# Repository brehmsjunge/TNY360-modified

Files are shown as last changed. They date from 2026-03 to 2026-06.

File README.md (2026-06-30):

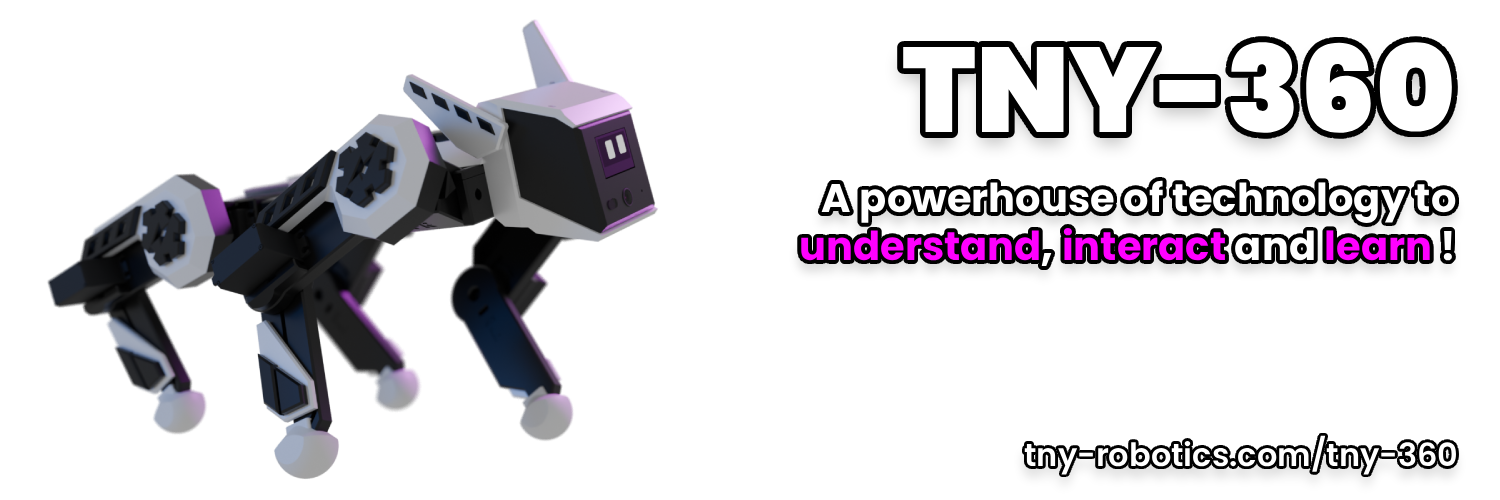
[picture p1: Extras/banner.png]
Banner


<div align="center">

# TNY-360 Modified — by Fuffel






**A modified fork of the TNY-360 open-source quadruped robot.**  
**Goal: Transform T360 into an autonomous scout & rescue platform.**

[🌐 Original Project](https://tny-robotics.com/tny-360) • [📖 Original Docs](https://tny-robotics.com/docs/tny-360/) • [💬 Discord](https://discord.gg/XGABkx5A4y) • [👤 FurWaz / Paul Loisil](https://instagram.com/furwaz_)

</div>

---

## ⚠️ This is a Fork

This repository is a **personal modification** of the original [TNY-360 by Paul Loisil / FurWaz (TNY Robotics)](https://github.com/TNY-Robotics/TNY-360).

All credit for the original robot design, firmware architecture, electronics, and documentation goes to **Paul Loisil and the TNY Robotics team**.  
This fork documents my own modifications and extensions on top of their work.

---

## 🔧 My Modifications

🚧 In Progress

- USB Serial Dashboard Transport (SerialTransport.hpp/.cpp) -> Access the robot dashboard over USB instead of WiFi only.
- Desktop Dashboard App -> A desktop application wrapping the existing WebPortal dashboard, with a switchable connection mode —> WiFi (WebSocket, same as today) or USB Serial (no need to swap WiFi networks).

📋 Planned

Active Cooling
- 2x 30x30mm 12V fans mounted on the top cover -> One intake (cold air in), one exhaust (warm air out) —> airflow across the Buck Converter and PCBs / New top cover design with fan cutouts (OpenSCAD, replacing the logo cover).
- Arduino I2C Sensor Integration -> Arduino Uno as I2C sensor node (LiDAR data), feeding into the TNY-360 mainboard via the dorsal expansion port / Later upgrade: Arduino Uno Q (Linux + MCU) for on-device AI processing.
- LiDAR + Thermal Camera Expansion -> For autonomous navigation (SLAM) and person detection
- Autonomous Navigation (SLAM) -> Path planning + obstacle avoidance using LiDAR data / Target: Arduino Uno Q running ROS2 / Nav2 as master, TNY-360 mainboard as movement slave.
- Reinforcement Learning Gait -> Teaching T360 to walk using AI instead of pre-programmed gaits.

---

## 🚀 Getting Started

For building and assembling the base robot, **follow the original guide:**

<div align="center">

> ### **[👉 Original Step-by-Step Guide by TNY Robotics 👈](https://tny-robotics.com/docs/tny-360/practical-guide/sourcing)**

</div>

For my modifications, see the relevant folders and their own READMEs:
- `Firmware/src/network/SerialTransport.cpp` — USB Serial Transport
- `CAD/cooling/` — Fan cover OpenSCAD files *(coming soon)*

---

## ⚙️ Original Hardware Specs

*(Unchanged from original — see [TNY Robotics documentation](https://tny-robotics.com/docs/tny-360/) for full details)*

| Component | Spec |
|---|---|
| MCU | ESP32-S3 N16R8 |
| Power | 3S LiPo (6x Samsung INR18650-25R) |
| Legs | 12x MG996R (modified with Op-Amp feedback PCB) |
| Head | 2x SG-90 Micro Servos |
| Vision | OV2640 Camera |
| Distance | VL53L0X ToF LiDAR |
| IMU | MPU6050 |
| Display | SH1106 OLED |
| Audio | I2S MEMS Mic + Speaker |

---

## 📂 Repository Structure

- `BOM/` — Bill of Materials (original)
- `CAD/` — Hardware files (original + my additions in `CAD/cooling/`)
- `Electronics/PCBs/` — PCB Designs (original)
- `Firmware/` — Codebase with my modifications on top of the original
- `Firmware/src/network/SerialTransport.cpp` — USB Serial Transport (my addition)

---

## 📄 License & Credits

**Original TNY-360** by [Paul Loisil / FurWaz](https://instagram.com/furwaz_) — [TNY Robotics](https://tny-robotics.com)  
**This fork** by Fuffel (Felix Brehm)

Licensed under **CC BY-NC-SA 4.0** — non-commercial use, attribution required, share alike.



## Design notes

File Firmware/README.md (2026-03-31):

# Firmware

Welcome to the TNY-360 Firmware directory! This is where all the code that powers the TNY-360 robot lives.

The firmware is built on **PlatformIO** using the **ESP-IDF** framework.

## Quick Start

### Prerequisites
1.  **VS Code** installed.
2.  **PlatformIO** extension installed in VS Code.

### Installation
1.  **Clone** this repository:
    ```bash
    git clone --recursive https://github.com/TNY-Robotics/TNY-360.git
    ```
2.  **Open** the `Firmware/` folder in VS Code.
3.  **Connect** your ESP32-S3 N16R8 via USB.
4.  **Upload:** Click the generic "Arrow" icon (➡️) in the PlatformIO bottom bar to Build & Flash.

> **Note:** If you are missing drivers, run `git submodule update --init --recursive` to pull the TNY-Robotics custom components.

---

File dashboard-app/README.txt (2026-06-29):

TNY-360 Dashboard Desktop App
==============================

A native Windows desktop application for controlling the TNY-360 quadruped robot
without needing a browser or switching network connections manually.

HOW IT WORKS
-------------
- The app bundles the existing WebPortal (Nuxt/Vue.js) and serves it locally via
  a built-in HTTP server on http://127.0.0.1:3333
- It connects to the TNY-360 via WebSocket on ws://192.168.4.1:5621 (default AP IP)
- The robot IP is set automatically via localStorage on first launch

REQUIREMENTS
-------------
- Windows 10/11
- Node.js and npm (for building)
- TNY-360 robot powered on and in Access Point (AP) WiFi mode
- PC connected to the TNY-360 WiFi network

BUILD FROM SOURCE
------------------
1. Build the WebPortal:
   cd Firmware/extras/WebPortal
   npm install
   npm run generate

2. Build the Electron app:
   cd dashboard-app
   npm install
   npx electron-builder

   Output: dashboard-app/dist/TNY-360 Dashboard Setup 1.0.0.exe

3. Run the installer and launch "TNY-360 Dashboard" from the desktop or start menu.

USAGE
------
1. Power on the TNY-360
2. Connect your PC to the TNY-360 WiFi network
3. Open the TNY-360 Dashboard app
4. The app will automatically connect to the robot at 192.168.4.1

PROJECT STRUCTURE
------------------
dashboard-app/
  main.js        - Electron main process, HTTP server, window setup
  preload.js     - Electron preload script (bridge for future USB Serial)
  package.json   - Node.js project config + electron-builder config

The WebPortal files are bundled from:
  Firmware/extras/WebPortal/.output/public/
(generated via "npm run generate" in the WebPortal directory)

TECHNICAL NOTES
----------------
- The app uses a local HTTP server instead of file:// protocol because Nuxt
  generates absolute asset paths (/_nuxt/...) that don't work with Electron's
  file:// loader.
- On first load, the app injects localStorage.setItem('fallback_ip', '192.168.4.1')
  so the WebPortal SDK connects to the correct robot IP instead of 127.0.0.1.
- USB Serial support is planned for a future version (SerialTransport.hpp is
  already implemented on the firmware side).

PLANNED FEATURES
-----------------
- USB Serial connection (no WiFi needed)
- WiFi <-> USB toggle in the UI
- Custom IP input dialog

CREDITS
--------
- TNY-360 robot & WebPortal: Paul Loisil (FurWaz) / TNY Robotics
  https://github.com/TNY-Robotics/TNY-360
- Dashboard Desktop App: Community contribution

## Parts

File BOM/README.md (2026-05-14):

# Bill Of Material

Here's the raw List of components you need to build your own TNY-360 robot.

You can also find a more user-friendly version of this list on the [TNY-360 Documentation](https://tny-robotics.com/docs/tny-360/practical-guide/sourcing/) as well as guides and manuals to help you source, print, assemble, and set up your TNY-360!

- List of [Screws and Inserts](./Screws.md)

- List of [Cables](./Cables.md)

- List of [PCBs](./PCBs.md)

- List of [Components](./Components.md)

*Have fun building your robot!*

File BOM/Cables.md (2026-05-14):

# Cables

Here's a list of all cables needed to wire up your TNY-360.

A complete kit of JST-PH wires is also linked below for easier sourcing, instead of buying each cable independently.

### Assembly guide

To learn how to fully assemble you TNY-360, check out the [TNY-360 Documentation](https://tny-robotics.com/docs/tny-360/practical-guide/sourcing/). A more user-friendly list of all the cables needed is also available here.

| Type | Pins | Length | Quantity | Location | Link |
| :--- | :--: | :----- | :---: | :--- | :--- |
| JST-PH |  3 | 100 mm | 4 | Motor Driver -> Paw Board | [Click here](https://s.click.aliexpress.com/e/_c3BIp6Ux) |
| JST-PH |  2 | 100 mm | 1 | Motor Driver -> Main Board | [Click here](https://s.click.aliexpress.com/e/_c3BIp6Ux) |
| JST-PH |  5 | 100 mm | 1 | Motor Driver -> Main Board | [Click here](https://s.click.aliexpress.com/e/_c3BIp6Ux) |
| JST-PH |  4 | 100 mm | 4 | Analog Reader -> Paw Board | [Click here](https://s.click.aliexpress.com/e/_c3BIp6Ux) |
| JST-PH |  7 | 100 mm | 1 | Analog Reader -> Main Board | [Click here](https://s.click.aliexpress.com/e/_c3BIp6Ux) |
| JST-PH (PIGTAIL) |  4 | 200 mm | 1 | IMU -> Paw Board | [Click here](https://s.click.aliexpress.com/e/_c44pILQb) |
| JST-PH |  4 | 200 mm | 2 | Plug Board -> Power & Main Board | [Click here](https://s.click.aliexpress.com/e/_c3BIp6Ux) |
| JST-PH |  2 | 200 mm | 2 | Plug Board -> Power & Main Board | [Click here](https://s.click.aliexpress.com/e/_c3BIp6Ux) |
| JST-PH (PIGTAIL) |  4 | 50 mm  | 1 | SH1106 -> Main Board | [Click here](https://s.click.aliexpress.com/e/_c44pILQb) |
| JST-PH (PIGTAIL) |  3 | 50 mm  | 2 | TTP23 -> Main Board | [Click here](https://s.click.aliexpress.com/e/_c44pILQb) |
| JST-PH (PIGTAIL) |  4 | 50 mm  | 1 | VL53L0X -> Main Board | [Click here](https://s.click.aliexpress.com/e/_c44pILQb) |
| JST-PH (PIGTAIL) |  5 | 50 mm  | 1 | I2S Mic. -> Main Board | [Click here](https://s.click.aliexpress.com/e/_c44pILQb) |
| JST-PH (PIGTAIL) |  2 | 450 mm | 4 | Contact Switch -> Paw Board | [Click here](https://s.click.aliexpress.com/e/_c44pILQb) |
| JST-XH (PIGTAIL) |  4 | 100 mm | 8 | Shoulder Servo -> Paw Board | [Click here](https://s.click.aliexpress.com/e/_c3WRxkg7) |
| JST-XH (PIGTAIL) |  4 | 300 mm | 4 | Leg Servo -> Paw Board | [Click here](https://s.click.aliexpress.com/e/_c3WRxkg7) |
| JST-XH (PIGTAIL) |  4 | 300 mm | 4 | Leg Servo -> Paw Board | [Click here](https://s.click.aliexpress.com/e/_c3WRxkg7) |
| 16 AWG Wire | | 100 mm | 3 | DC-DC Converter -> Paw Board | [Click here](https://fr.aliexpress.com/item/1005006614755156.html) |

### Connectors
| Type | Quantity | Link |
| --- | --- | --- |
| Ring Crimp Connector | 6 | [Click here](https://s.click.aliexpress.com/e/_c2yxJCd5) |
| Dupont Connector | 4 | None - Use the ones from the MG996R motors :) |

### Complete kit

To simplify cable sourcing, you can alternatively buy only one JST-PH cable kit, and some JST-XH pigtail cables.

* Link to the [JST-PH Cables Kit](https://s.click.aliexpress.com/e/_c3AtPZ9h).
* Link to the [Dupont Connector Kit](https://fr.aliexpress.com/item/4001063470283.html);
* Link to the [JST-XH Pigtail Cables](https://s.click.aliexpress.com/e/_c3WRxkg7).

Please check that you selected the `XH-2.54mm version (4P)` before ordering.

### About the SH1106, TTP23, VL53L0X and I2S Mic. cables

Since these cables are going to be soldered directly on the component, you can buy a 100mm cable and cut it in half to make 2x 50mm pigtail cables. This reduces the number of cables to order.

### About the contact switch cable

The contact switch cable should end with a 3-pin Dupont connector (the standard 2.54mm arduino connectors), with the middle pin empty.

No such cable (JST-PH 2-Pins to 2.54 mm Dupont 3 Pins) exists on the web, so you will probably have to make it yourself. A complete guide on how to create that cable is available *(or will be available)* on the [TNY-360 Documentation](https://tny-robotics.com/docs/tny-360).

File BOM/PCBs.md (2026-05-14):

# PCBs

Here's a list of all PCBs needed to build your TNY-360. You can find all design files in the [GitHub repository](https://github.com/TNY-Robotics/TNY-360/tree/main/Electronics/PCBs).

### Assembly guide

To learn how to fully assemble you TNY-360, check out the [TNY-360 Documentation](http://localhost:3000/docs/tny-360/practical-guide/sourcing/). A more user-friendly list of all the PCBs needed is also available here.

### PCBs list

| PCB | Purpose | Quantity | Files |
| --- | --- | :---: | --- |
| Main Board | Robot brain and main controller | 1 | [GitHub PCB Files](https://github.com/TNY-Robotics/TNY-360/tree/main/Electronics/PCBs/Main) |
| Analog Reader | Sensor interface board | 1 | [GitHub PCB Files](https://github.com/TNY-Robotics/TNY-360/tree/main/Electronics/PCBs/Analog%20Reader) |
| Motor Driver  | Motor control board | 1 | [GitHub PCB Files](https://github.com/TNY-Robotics/TNY-360/tree/main/Electronics/PCBs/Motor%20Driver) |
| Power Board | Power distribution | 1 | [GitHub PCB Files](https://github.com/TNY-Robotics/TNY-360/tree/main/Electronics/PCBs/Power) |
| Paw Board | Legs multiplexing and power management | 2 | [GitHub PCB Files](https://github.com/TNY-Robotics/TNY-360/tree/main/Electronics/PCBs/Paw) |
| Plug Board | Universal Mount interface | 1 | [GitHub PCB Files](https://github.com/TNY-Robotics/TNY-360/tree/main/Electronics/PCBs/Universal%20Mount) |
| Servo Board | Custom MG996R servo modification board | 12 | [GitHub PCB Files](https://github.com/TNY-Robotics/TNY-360/tree/main/Electronics/PCBs/Servomotor) |

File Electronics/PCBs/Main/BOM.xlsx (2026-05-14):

No. | Quantity | Comment | Designator | Footprint | Value | Manufacturer Part | Manufacturer | Supplier Part | Supplier
1 | 1 | XL-5050RGBC-2812B | 2812B | LED-SMD_4P-L5.0-W5.0-BL_XL-5050RGBC |  | XL-5050RGBC-2812B | XINGLIGHT(成兴光) | C2843785 | LCSC
2 | 2 | AMS1117-3.3 | AMS3.3,AMS3.3ESP | SOT-223-3_L6.5-W3.4-P2.30-LS7.0-BR |  | AMS1117-3.3 | AMS | C6186 | LCSC
3 | 2 | B3B-PH-K-S(LF)(SN) | BTN_LEFT,BTN_RIGHT | CONN-TH_B3B-PH-K-S |  | B3B-PH-K-S(LF)(SN) | JST | C131339 | LCSC
4 | 1 | HX 0.5-24PIN XGXJ-H2.0 | CAM | FPC-SMD_24P-P0.50_HX-0.5-24PIN-XGXJ-H2.0 |  | HX 0.5-24PIN XGXJ-H2.0 | hanxia(韩下) | C19269981 | LCSC
5 | 3 | 220pF | CASIG,CSPKRG,CSPKRV | C0603 | 220pF | CL10B221KB8NNNC | SAMSUNG(三星) | C1603 | LCSC
6 | 4 | 10uF | CAVDD2,CCH340,CDVDD2,CESP2 | C0603 | 10uF | CL10A106MA8NRNC | SAMSUNG(三星) | C96446 | LCSC
7 | 8 | 100nF | CAVDD,CAVDD1,CCAM14,CCSI_RST,CDVDD1,CESP1,CINL,CSPKR | C0603 | 100nF | CC0603KRX7R9BB104 | YAGEO(国巨) | C14663 | LCSC
8 | 1 | 15pF | CCAM8 | C0603 | 15pF | CL10C150JB8NNNC | SAMSUNG(三星) | C1644 | LCSC
9 | 1 | CH340C | CH340C | SOP-16_L10.0-W3.9-P1.27-LS6.0-BL |  | CH340C | WCH(南京沁恒) | C84681 | LCSC
10 | 3 | 1uF | CINR1,CUPEN1,CVREF | C0603 | 1uF | CL10A105KO8NNNC | SAMSUNG(三星) | C1592 | LCSC
11 | 1 | 10nF | CINR2 | C0603 | 10nF | 0603B103K500NT | FH(风华) | C57112 | LCSC
12 | 4 | B4B-PH-K-S(LF)(SN) | CN-BAT,CN-IMU,CN-LASER,CN-SCREEN | CONN-TH_B4B-PH-K-S |  | B4B-PH-K-S(LF)(SN) | JST | C131334 | LCSC
13 | 2 | B2B-PH-K-S(LF)(SN) | CN-EARS,CN-POWER | CONN-TH_B2B-PH-K-S |  | B2B-PH-K-S(LF)(SN) | JST | C131337 | LCSC
14 | 2 | B5B-PH-K-S(LF)(SN) | CN-MOTORS,MIC | CONN-TH_B5B-PH-K-S-LF-SN |  | B5B-PH-K-S(LF)(SN) | JST | C157993 | LCSC
15 | 1 | B7B-PH-K-S(LF)(SN) | CN-READER | CONN-TH_B7B-PH-K-S-LF-SN |  | B7B-PH-K-S(LF)(SN) | JST | C157981 | LCSC
16 | 1 | 470uF | CPGND | CAP-TH_BD8.0-P3.50-D0.6-FD | 470uF | GR477M025F14RR0VL4FP0 | Chengx(承兴) | C5154 | LCSC
17 | 2 | SS34 | D1,D2 | SMA_L4.3-W2.6-LS5.2-RD |  | SS34 | MDD(辰达半导体) | C8678 | LCSC
18 | 1 | ESP32-S3-WROOM-1U-N16R8 | ESP32-S3 | WIRELM-SMD_ESP32-S3-WROOM-1U |  | ESP32-S3-WROOM-1U-N16R8 | ESPRESSIF(乐鑫) | C3013946 | LCSC
19 | 3 | BLM18SG121TN1D | LAVDD,LSPKRG,LSPKRV | L0603 |  | BLM18SG121TN1D | muRata(村田) | C113030 | LCSC
20 | 1 | PAM8406DR | PAM8406 | SOIC-16_L9.9-W3.9-P1.27-LS6.0-BL |  | PAM8406DR | DIODES(美台) | C86270 | LCSC
21 | 2 | S8050 J3Y(RANGE:200-350) | QDTR,QRTS | SOT-23-3_L3.0-W1.7-P0.95-LS2.9-BR |  | S8050 J3Y(RANGE:200-350) | CJ(江苏长电/长晶) | C2146 | LCSC
22 | 2 | 1kΩ | RCAM17,RINR | R0603 | 1kΩ | RC0603FR-071KL | YAGEO(国巨) | C22548 | LCSC
23 | 3 | 10kΩ | RDTR,RRTS,RUPEN1 | R0603 | 10kΩ | 0603WAF1002T5E | UNI-ROYAL(厚声) | C25804 | LCSC
24 | 1 | 22kΩ | RPAM | R0603 | 22kΩ | 0603WAF2202T5E | UNI-ROYAL(厚声) | C31850 | LCSC
25 | 1 | 4.7kΩ | RRST | R0603 | 4.7kΩ | 0603WAF4701T5E | UNI-ROYAL(厚声) | C23162 | LCSC
26 | 4 | 2.2kΩ | RUPFA,RUPFL,RUPSA,RUPSL | R0603 | 2.2kΩ | 0603WAF2201T5E | UNI-ROYAL(厚声) | C4190 | LCSC
27 | 1 | 1.25mm-2P ZZ-MS | SPEAKER | CONN-TH_2P-P1.25_1.25MM-2P-ZZ-MS |  | 1.25mm-2P ZZ-MS | SHOU HAN(首韩) | C5368706 | LCSC
28 | 1 | TYPE-C16PIN | USB | USB-C-SMD_TYPE-C16PIN |  | TYPE-C16PIN | SHOU HAN(首韩) | C393939 | LCSC
29 | 1 | USBLC6-2SC6 | USBLC6 | SOT-23-6_L2.9-W1.6-P0.95-LS2.8-BL |  | USBLC6-2SC6 | ST(意法半导体) | C7519 | LCSC
30 | 1 | XC6206-1.2V | XC6206-1.2 | SOT-23-3_L3.0-W1.6-P1.90-LS2.8-BR |  | XC6206-1.2V | YONGYUTAI(永裕泰) | C49446790 | LCSC
31 | 1 | XC6206-2.8V | XC6206-2.8 | SOT-23-3_L2.9-W1.6-P1.90-LS2.8-BR |  | XC6206-2.8V | YONGYUTAI(永裕泰) | C2892669 | LCSC

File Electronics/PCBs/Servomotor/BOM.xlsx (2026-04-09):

No. | Quantity | Comment | Designator | Footprint | Value | Manufacturer Part | Manufacturer | Supplier Part | Supplier
1 | 1 | 100nF | C1 | C0402 | 100nF | CL05B104KO5NNNC | SAMSUNG(三星) | C1525 | LCSC
2 | 1 | OPA333AIDCKT | U1 | SC-70-5_L2.0-W1.3-P0.65-LS2.1-BL |  | OPA333AIDCKT | TI(德州仪器) | C2057324 | LCSC

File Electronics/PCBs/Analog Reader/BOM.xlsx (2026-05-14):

No. | Quantity | Comment | Designator | Footprint | Value | Manufacturer Part | Manufacturer | Supplier Part | Supplier
1 | 1 | 74HC4067PW,118 | 74HC4067 | TSSOP-24_L7.8-W4.4-P0.65-LS6.4-BL |  | 74HC4067PW,118 | Nexperia(安世) | C179326 | LCSC
2 | 16 | 1uF | C1,C2,C3,C4,C5,C6,C7,C8,C9,C10,C11,C12,C13,C14,C15,C16 | C0603 | 1uF | CL10A105KB8NNNC | SAMSUNG(三星) | C15849 | LCSC
3 | 1 | 100nF | C-74HC | C0805 | 100nF | CC0805KRX7R9BB104 | YAGEO(国巨) | C49678 | LCSC
4 | 4 | B4B-PH-K-S(LF)(SN) | CN-BL,CN-BR,CN-FL,CN-FR | CONN-TH_B4B-PH-K-S |  | B4B-PH-K-S(LF)(SN) | JST | C131334 | LCSC
5 | 1 | B7B-PH | CN-SIGNAL | CONN-TH_B7B-PH-K-S-LF-SN |  | B7B-PH | JST | C157981 | LCSC
6 | 16 | 4.7kΩ | R1,R2,R3,R4,R5,R6,R7,R8,R9,R10,R11,R12,R13,R14,R15,R16 | R0603 | 4.7kΩ | 0603WAF4701T5E | UNI-ROYAL(厚声) | C23162 | LCSC

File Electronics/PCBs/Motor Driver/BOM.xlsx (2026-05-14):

No. | Quantity | Comment | Designator | Footprint | Value | Manufacturer Part | Manufacturer | Supplier Part | Supplier
1 | 2 | 100nF | C-LS,C-PCA | C0805 | 100nF | CC0805KRX7R9BB104 | YAGEO(国巨) | C49678 | LCSC
2 | 4 | B3B-PH-K-S(LF)(SN) | CN-BL,CN-BR,CN-FL,CN-FR | CONN-TH_B3B-PH-K-S |  | B3B-PH-K-S(LF)(SN) | JST | C131339 | LCSC
3 | 1 | B2B-PH-K-S(LF)(SN) | CN-EARS | CONN-TH_B2B-PH-K-S |  | B2B-PH-K-S(LF)(SN) | JST | C131337 | LCSC
4 | 1 | B5B-PH-K-S(LF)(SN) | CN-SIGNAL | CONN-TH_B5B-PH-K-S-LF-SN |  | B5B-PH-K-S(LF)(SN) | JST | C157993 | LCSC
5 | 1 | PCA9306DCUR | PCA9306 | SSOP-8_L2.0-W2.3-P0.50-LS3.1-BR |  | PCA9306DCUR | TI(德州仪器) | C33196 | LCSC
6 | 1 | PCA9685PW,118 | PCA9685 | TSSOP-28_L9.7-W4.4-P0.65-LS6.4-TL | - | PCA9685PW,118 | NXP(恩智浦) | C2678753 | LCSC
7 | 14 | 220Ω | R1,R2,R3,R4,R5,R6,R7,R8,R9,R10,R11,R12,R13,R14 | R0805 | 220Ω | 0805W8F2200T5E | UNI-ROYAL(厚声) | C17557 | LCSC
8 | 1 | 200kΩ | R-LS | R0805 | 200kΩ | 0805W8F2003T5E | UNI-ROYAL(厚声) | C17539 | LCSC
9 | 2 | 2.2kΩ | RUP1,RUP2 | R0805 | 2.2kΩ | 0805W8F2201T5E | UNI-ROYAL(厚声) | C17520 | LCSC

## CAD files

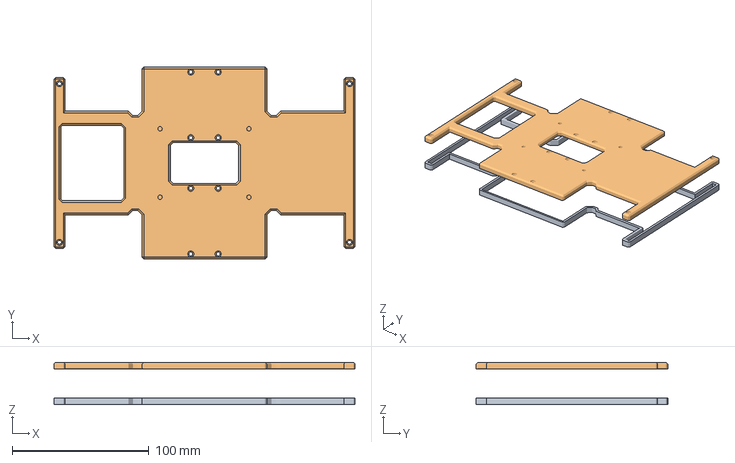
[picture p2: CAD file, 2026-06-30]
CAD/01_Parts/Spacer.FCStd
220.0 x 140.0 x 31.0 mm
Torso - Top

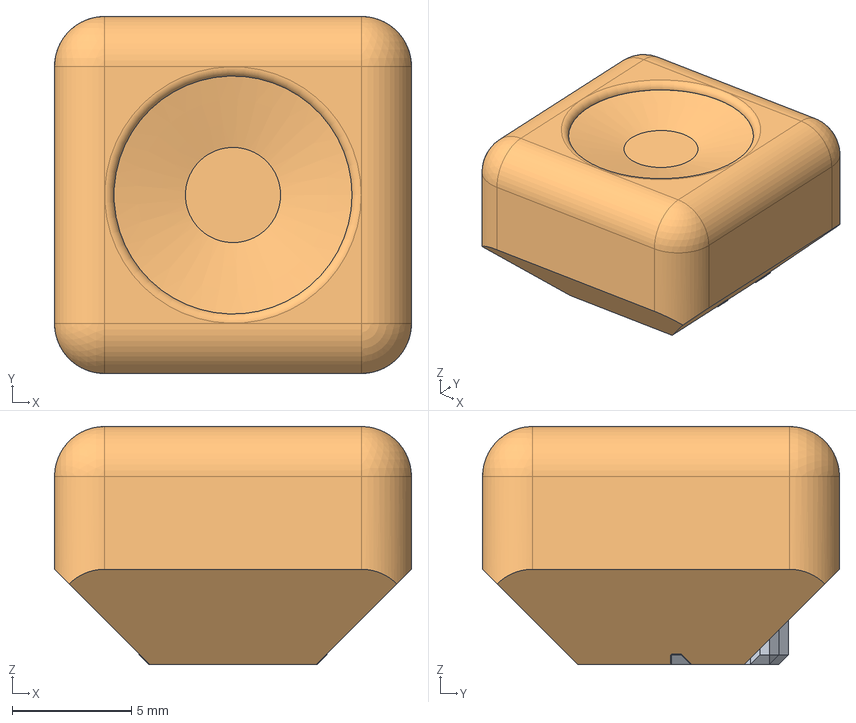
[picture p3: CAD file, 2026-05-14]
CAD/03_Common/Master_Clip.FCStd
15.0 x 15.0 x 10.0 mm
Clip
ClipHelper

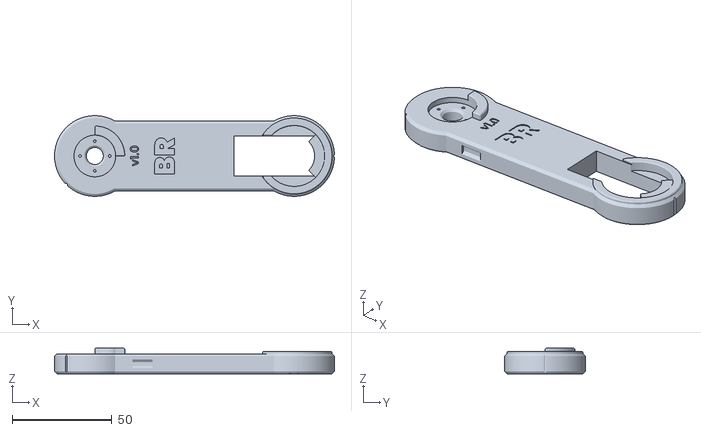
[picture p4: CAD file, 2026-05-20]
CAD/Exported/STLs/Leg - Top BR.stl
140.5 x 40.5 x 12.8

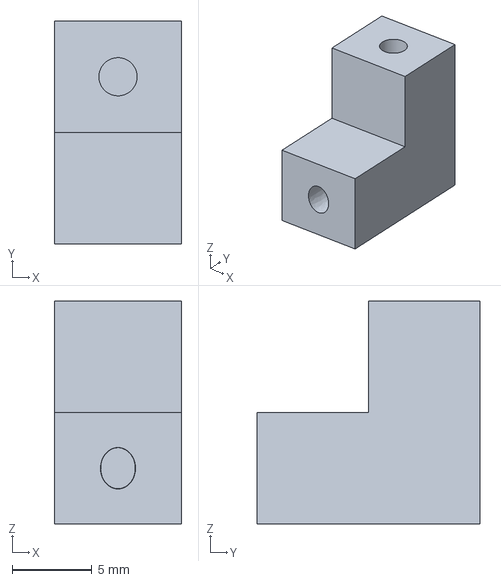
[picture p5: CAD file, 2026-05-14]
CAD/Settings.FCStd
8.00 x 14.0 x 14.0 mm

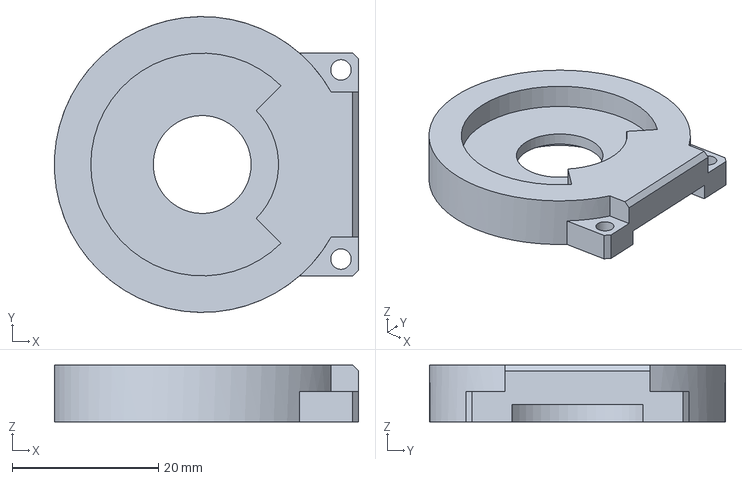
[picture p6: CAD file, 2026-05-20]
CAD/01_Parts/Shoulders.FCStd
41.6 x 40.5 x 7.80 mm

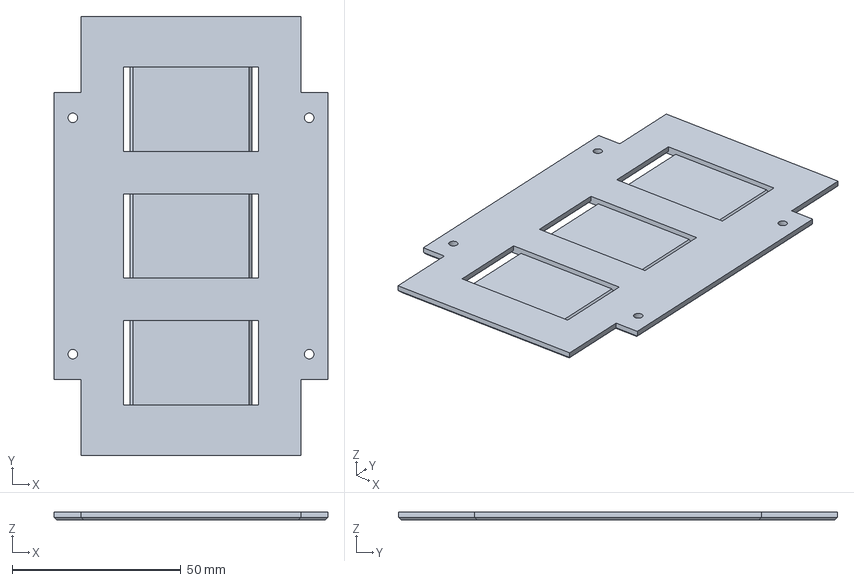
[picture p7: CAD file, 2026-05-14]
CAD/01_Parts/Battery.FCStd
81.0 x 130.0 x 2.40 mm

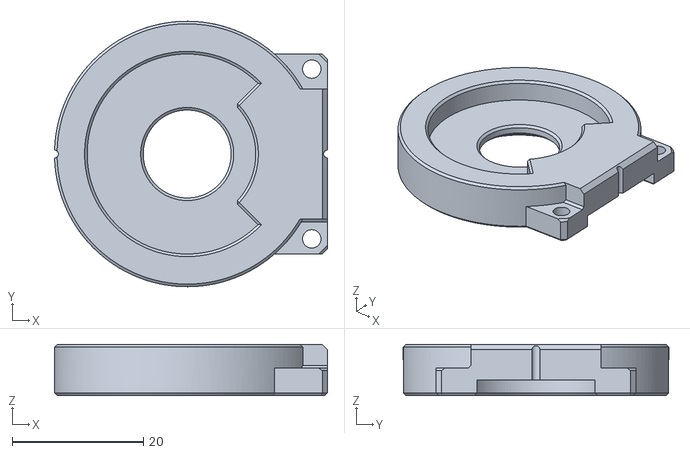
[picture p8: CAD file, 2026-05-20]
CAD/Exported/STLs/Shoulder - Top.stl
41.6 x 40.5 x 7.80

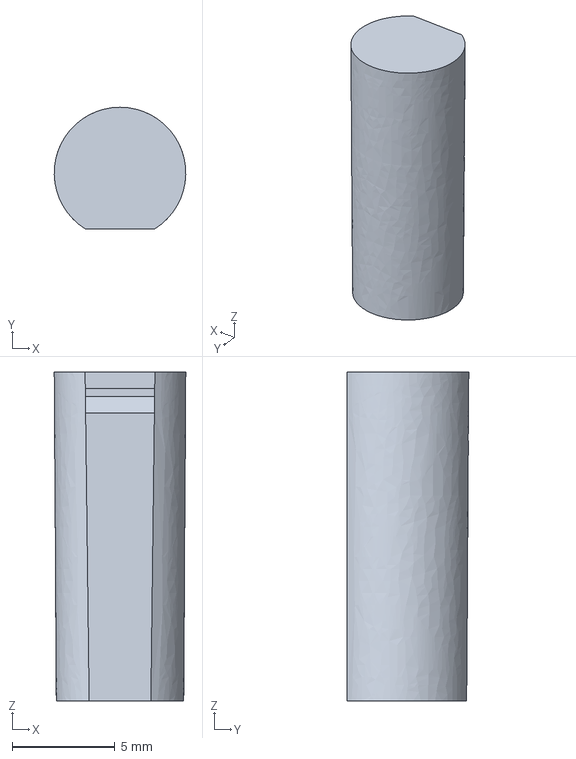
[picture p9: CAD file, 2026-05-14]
CAD/01_Parts/Torso-Shoulder_Pin.FCStd
6.40 x 5.91 x 16.0 mm

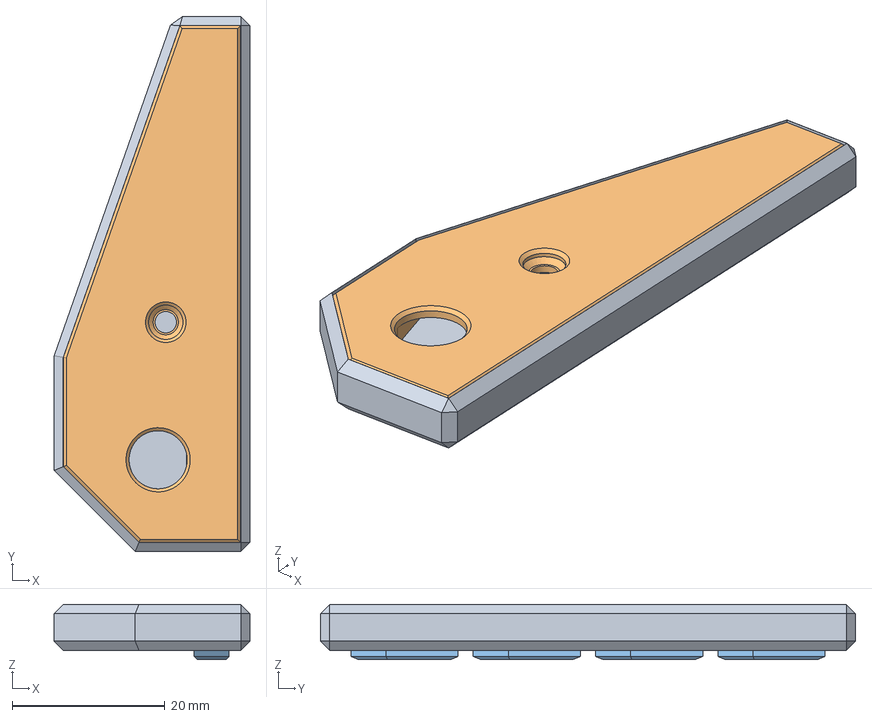
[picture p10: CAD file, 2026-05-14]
CAD/01_Parts/Ears.FCStd
25.6 x 70.0 x 7.20 mm
Front - L
Back - L
Deco - L

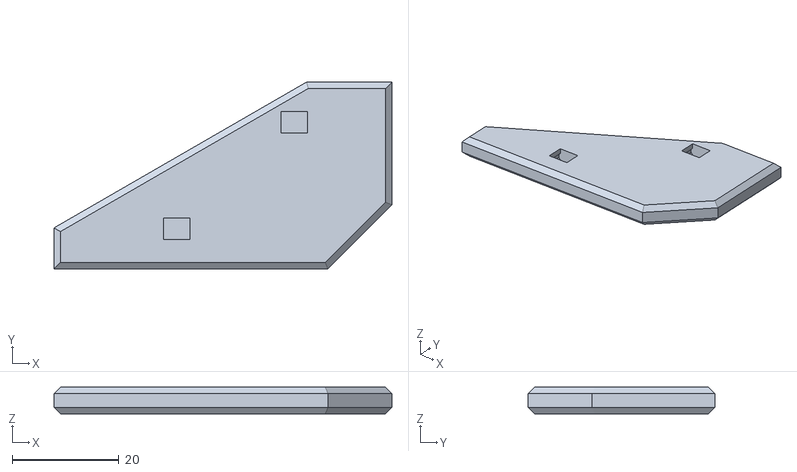
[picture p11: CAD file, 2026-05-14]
CAD/Exported/STLs/Leg - Bottom L - Cover.stl
63.3 x 35.0 x 5.00

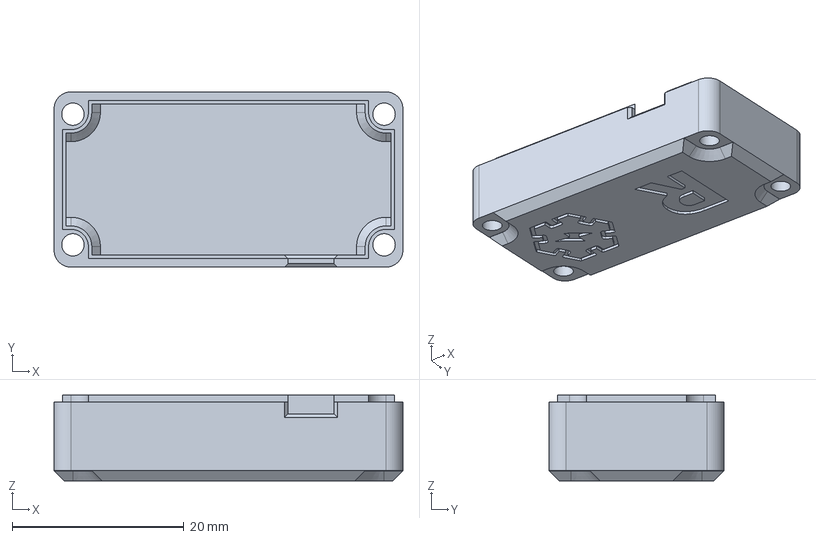
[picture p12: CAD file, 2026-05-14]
CAD/01_Parts/Servo_Cover.FCStd
40.6 x 20.4 x 10.0 mm

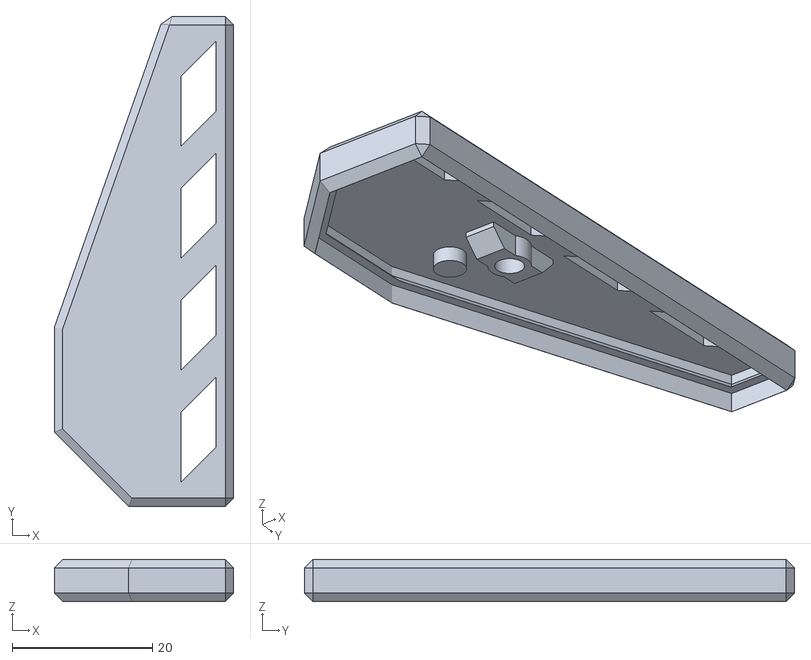
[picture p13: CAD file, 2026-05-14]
CAD/Exported/STLs/Ears - Front R.stl
25.6 x 70.0 x 6.00

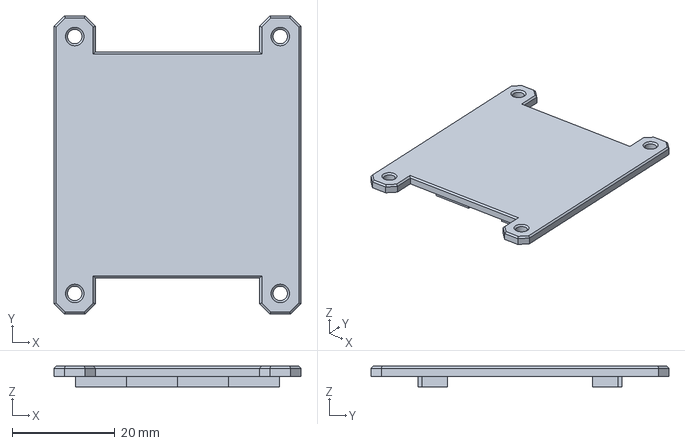
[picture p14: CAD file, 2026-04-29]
CAD/01_Parts/Torso.FCStd
48.0 x 58.0 x 4.00 mm

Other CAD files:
CAD/00_Assemblies/Main.FCStd
CAD/Exported/STLs/Leg - Top FR.stl
CAD/01_Parts/Leg_Top.FCStd
CAD/Exported/STLs/Leg - Top BL.stl
CAD/Exported/STLs/Leg - Top FL.stl
CAD/01_Parts/Back.FCStd
CAD/01_Parts/Leg_Bottom.FCStd
CAD/Exported/STLs/Back - Bottom Clip.stl
CAD/Exported/STLs/Back - Cover.stl
CAD/Exported/STLs/Battery - LipoHolder Base.stl
CAD/Exported/STLs/Clip - Helper.stl
CAD/Exported/STLs/Clip.stl
CAD/Exported/STLs/Ears - Back L.stl
CAD/Exported/STLs/Ears - Back R.stl
CAD/Exported/STLs/Ears - Deco L.stl
CAD/Exported/STLs/Ears - Deco R.stl
CAD/Exported/STLs/Ears - Front L.stl
CAD/Exported/STLs/Head - Backplate.stl
CAD/Exported/STLs/Head - Bottom Cover.stl
CAD/Exported/STLs/Head - Camera Attach.stl
CAD/Exported/STLs/Head - Top Cover.stl
CAD/Exported/STLs/Head - Visor Plate.stl
CAD/Exported/STLs/Head - Visor.stl
CAD/Exported/STLs/Leg - Bottom Ball.stl
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

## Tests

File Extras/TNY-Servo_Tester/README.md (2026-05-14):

# TNY-Servo Tester

This project is for people building their own TNY Servomotors.

It provides a simple way to ensure the servomotors work correctly before they are installed in the robot.

---

> [!NOTE]  
> The code is dirty. It is not meant to be used as a reference for good coding practices, but rather as a quick and dirty solution to test the servomotors.

## Hardware

The tester is made to work on an ESP32-S3 Dev Board, here's the pinout:

| ESP32-S3 Pin | Function |
| --- | --- |
| GPIO 48 | LED Control (WS2812) |
| GPIO 42 | Servo Signal (PWM) |
| GPIO 02 | Servo Feedback (ADC1_CH1) |

While powering up a motor from the ESP32-S3 Dev Board is not recommended, it's acceptable to power the servo from the board's **5V** & **GND** pins for testing purposes. The servo will only draw a small amount of current during the test (as long as you don't block its movement), so it should be safe to power it from the board.

For easier testing, connect a 4-Pin Dupont 2.54mm header to the ESP32-S3 Dev Board, and then connect the TNY-Servo's JST-XH connector to the header. This will allow you to easily connect and disconnect the servo for testing.

> [!WARNING]  
> Make sure to connect the **GROUND** pin of the servo first (slightly tilt the connector when plugging it in) to avoid damaging the servo or the ESP32-S3 Dev Board. If power is applied to the servo before the ground connection is made, it can cause the current to come back through the servo's internal circuitry. 

## Software

The code is written in C++ using the ESP-IDF framework. It uses the LEDC peripheral to generate the PWM signal for the servo and the ADC to read the feedback from the servo.

## Usage

1. Connect the servo to the ESP32-S3 Dev Board according to the pinout above.
2. Power on or reset the ESP32-S3 Dev Board.
3. Wait for the code to run and observe the LED color and the servo movement.
4. For more detailed information on the test, check the serial output using a serial monitor.

### Testing sequence

The testing sequence is simple :
1. The servo will move to its minimum position (0°) and wait a little bit for the ADC reading to stabilize.
2. The servo will then move to its maximum position (180°) and wait again for the ADC reading to stabilize.
3. Finally, the servo will move back to its center position (90°) and wait for the ADC reading to stabilize.

At the end of the test, the code will check if the ADC readings are within the expected range, noise & order for the servo to be considered working correctly. Even if the servo is moving during the test, the feedback could still be incorrect, so wait for the test to finish and check the LED color to know if the servo is fully functional or not.

### LED Color Indication

While testing, the LED will display in **BLUE**. This indicates that the tester is running and the servo is being tested.

At the end of the test, the LED will change to **GREEN** if the servo is working correctly, or **RED** if there is an issue with the servo.

For more information on the test results, check the serial output.

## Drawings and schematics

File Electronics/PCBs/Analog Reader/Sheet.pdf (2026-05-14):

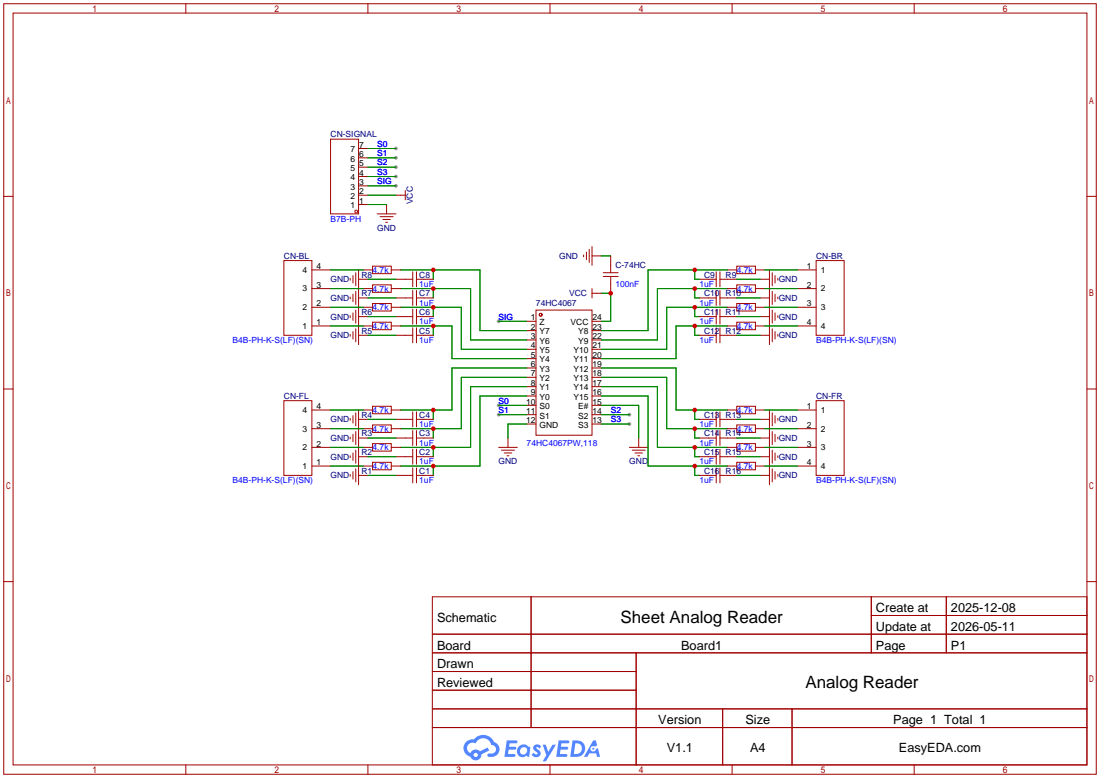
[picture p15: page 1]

Schematic | Sheet Analog Reader | Create at | 2025-12-08

Update at | 2026-05-11

Board | Board1 | Page | P1
Drawn | | Analog Reader
Reviewed

Version | Size | Page 1 Total 1
V1.1 | A4 | EasyEDA.com

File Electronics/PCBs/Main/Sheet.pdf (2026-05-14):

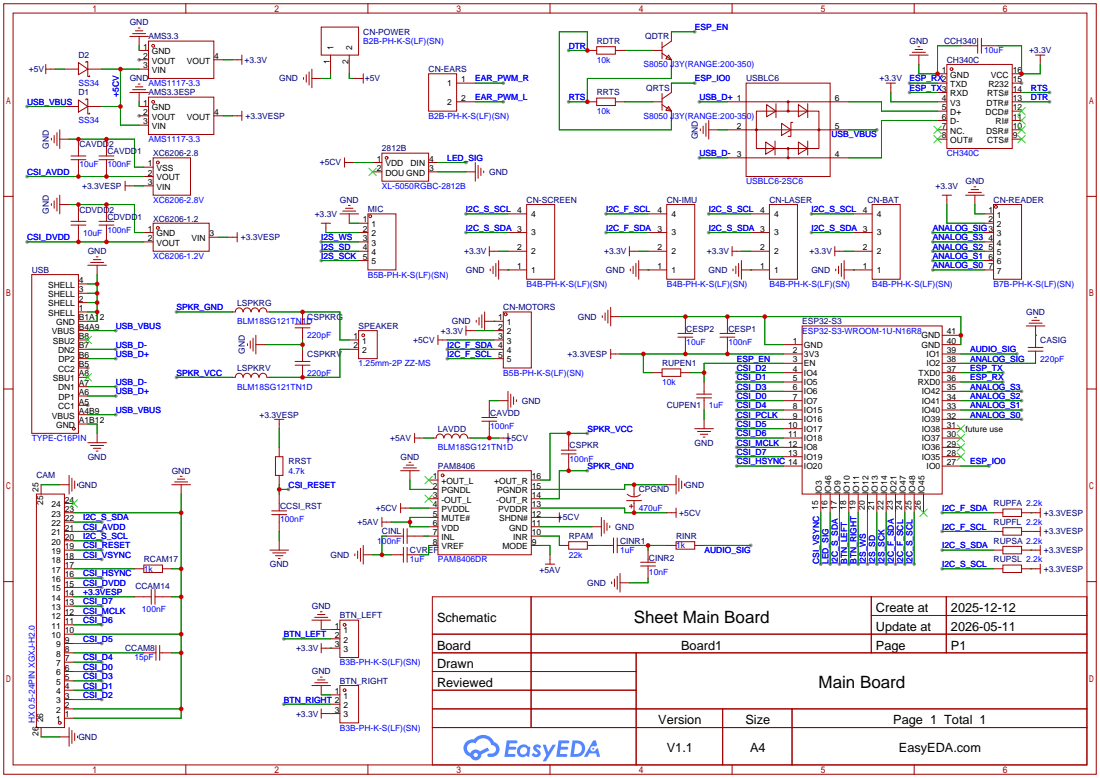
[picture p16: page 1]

DSR# 10 RI# 11 DCD# 12 DTR# 13 RTS# 14 R232 15 VCC 16

INR 10 GND 11 SHDN# 12 PVDDR 13 -OUT_R 14 PGNDR 15 +OUT_R 16

Schematic | Sheet Main Board | Create at | 2025-12-12

Update at | 2026-05-11

Board | Board1 | Page | P1
Drawn | | Main Board
Reviewed

Version | Size | Page 1 Total 1
V1.1 | A4 | EasyEDA.com

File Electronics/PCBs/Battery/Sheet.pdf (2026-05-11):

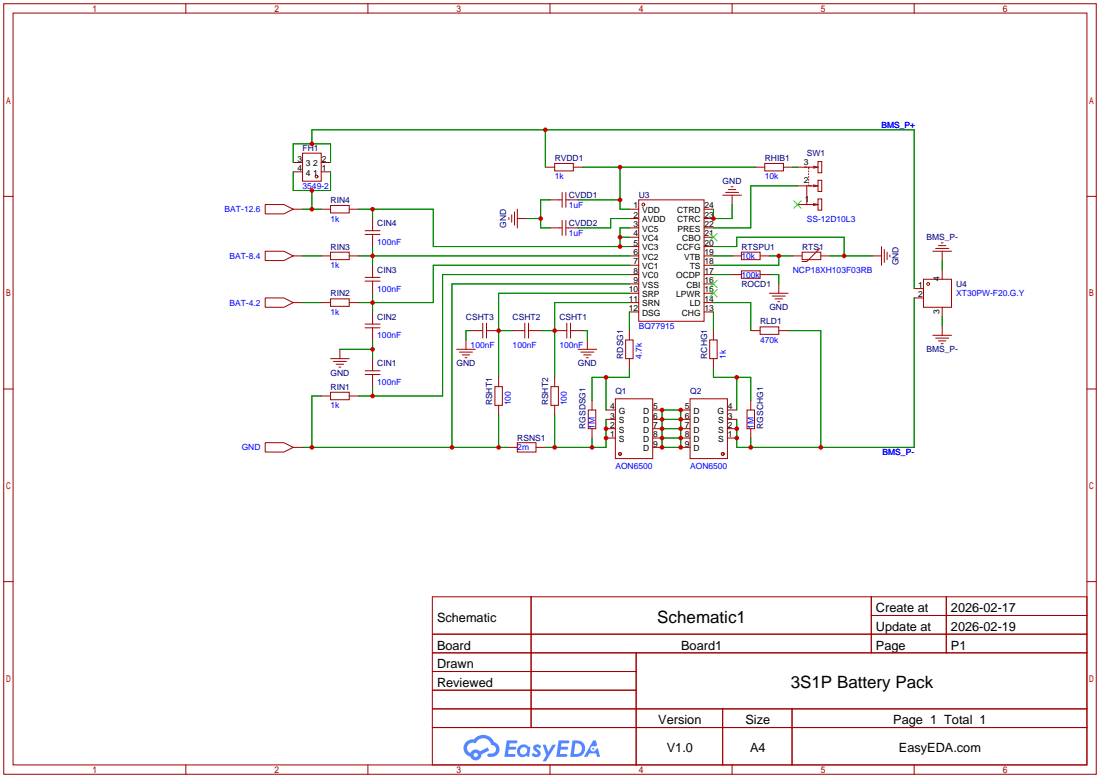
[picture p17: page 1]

Schematic | Schematic1 | Create at | 2026-02-17

Update at | 2026-02-19

Board | Board1 | Page | P1
Drawn | | 3S1P Battery Pack
Reviewed

Version | Size | Page 1 Total 1
V1.0 | A4 | EasyEDA.com

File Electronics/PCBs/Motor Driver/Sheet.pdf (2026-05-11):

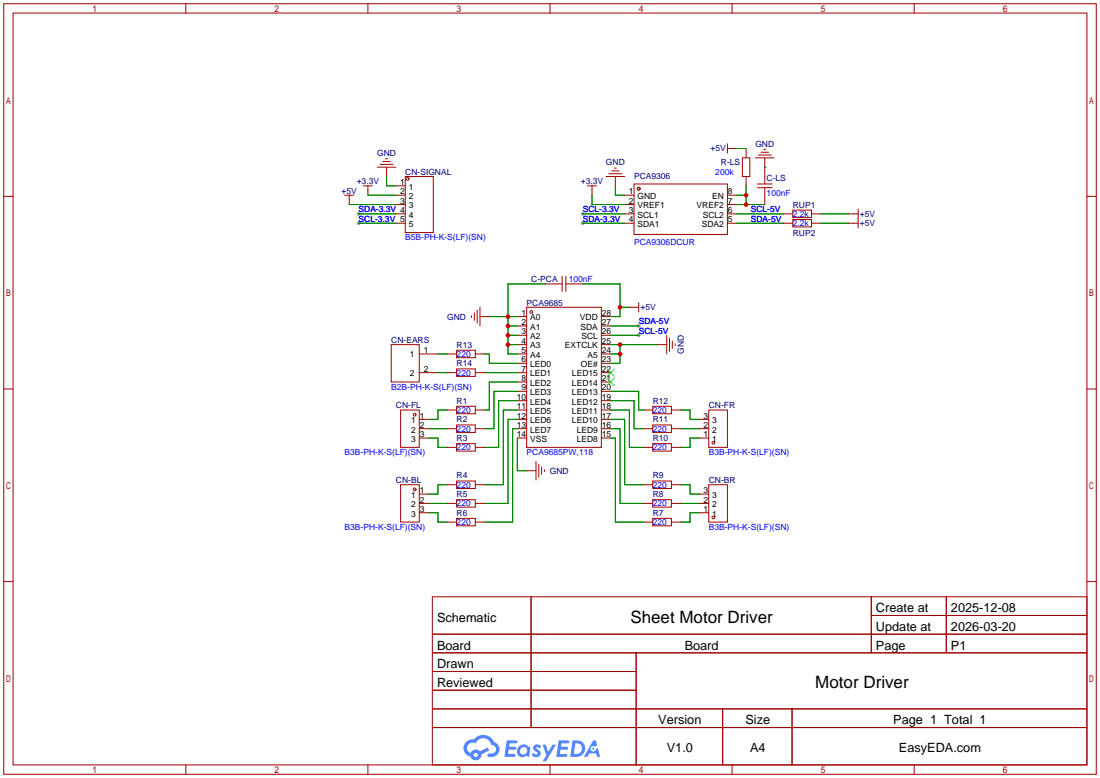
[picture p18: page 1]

Schematic | Sheet Motor Driver | Create at | 2025-12-08

Update at | 2026-03-20

Board | Board | Page | P1
Drawn | | Motor Driver
Reviewed

Version | Size | Page 1 Total 1
V1.0 | A4 | EasyEDA.com

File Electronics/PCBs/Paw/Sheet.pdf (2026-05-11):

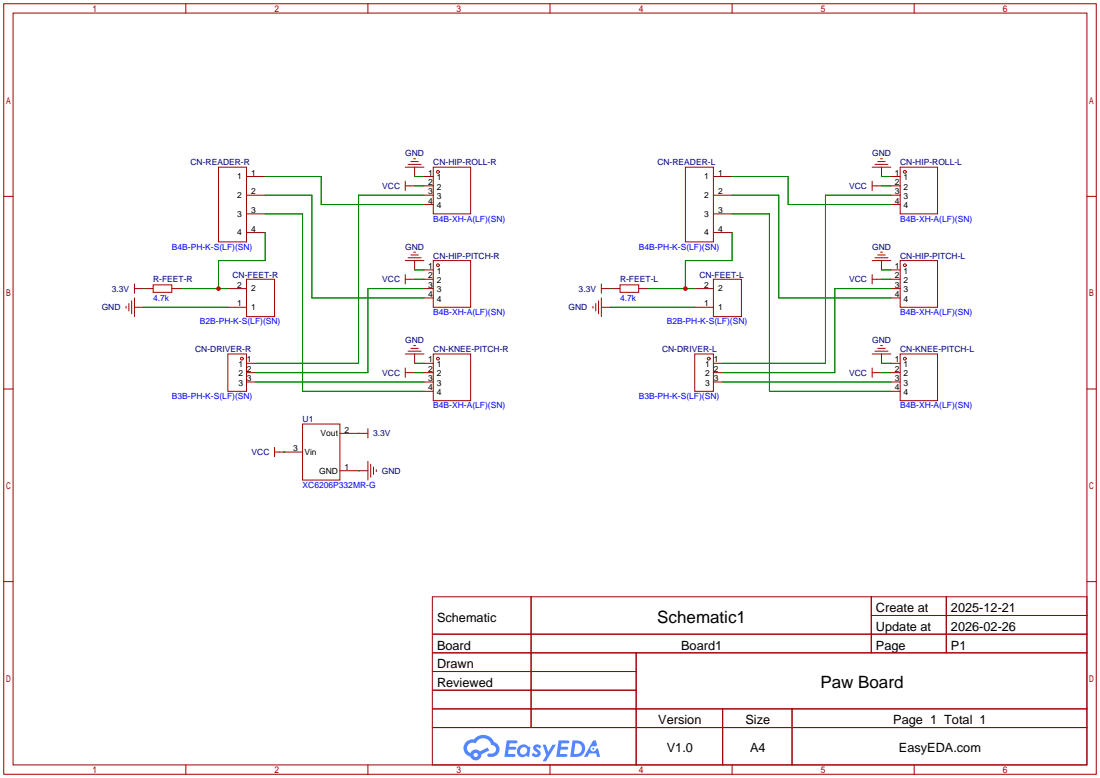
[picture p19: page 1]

Schematic | Schematic1 | Create at | 2025-12-21

Update at | 2026-02-26

Board | Board1 | Page | P1
Drawn | | Paw Board
Reviewed

Version | Size | Page 1 Total 1
V1.0 | A4 | EasyEDA.com

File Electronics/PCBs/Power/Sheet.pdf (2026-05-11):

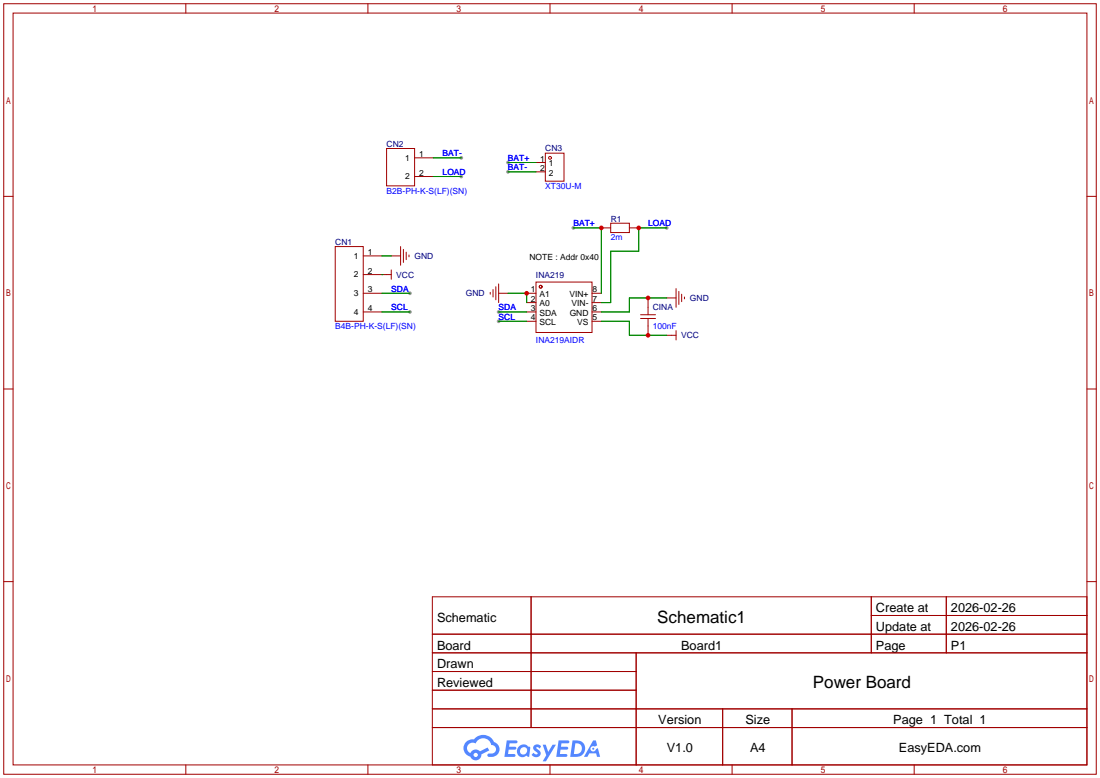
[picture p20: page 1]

Schematic | Schematic1 | Create at | 2026-02-26

Update at | 2026-02-26

Board | Board1 | Page | P1
Drawn | | Power Board
Reviewed

Version | Size | Page 1 Total 1
V1.0 | A4 | EasyEDA.com

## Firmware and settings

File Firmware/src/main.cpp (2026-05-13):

#include <freertos/FreeRTOS.h>
#include "common/Log.hpp"
#include "Robot.hpp"
#include "common/config.hpp"
#include "common/RPC.hpp"
#include "boot/BootManager.hpp"

static const char* TAG = "Main";

static Robot robot;
CameraDriver cam;
WiFiManager wifi;

#ifdef __cplusplus
extern "C" {
#endif
void app_main()
{
    // Check for special boot state (zero-calibration, pending update, etc.)
    if (BootManager::CheckForSpecialBoot())
    {
        // Special boot state detected.
        // The corresponding boot will be handled by the BootManager.
        // just return to avoid booting as normal (should not happen anyway)
        return;
    }

    LOG_INFO(TAG, "Initializing robot (FIRMWARE_VERSION=%s) ...", FIRMWARE_VERSION);

    if (Error err = robot.init(); err != Error::None)
    {
        LOG_ERROR(TAG, "Failed to initialize robot. Error : %s", ErrorToString(err));
        return;
    }

    LOG_INFO(TAG, "Robot initialized successfully.");

    // TEMPORARY : To avoid impossible position errors
    robot.getDecisionLoop().askBodyPosition(0, 0, DEFAULT_BODY_HEIGHT_M);
    robot.getDecisionLoop().askBodyRotation(0, 0, 0);
    robot.getDecisionLoop().askBodyVelocity(0, 0, 0);
    
    LOG_INFO(TAG, "Starting robot ...");

    if (Error err = robot.start(); err != Error::None)
    {
        LOG_ERROR(TAG, "Failed to start robot. Error : %s", ErrorToString(err));
        return;
    }

    LOG_INFO(TAG, "Robot started successfully !");

    // RPC::ExecuteThreadSafe<Error>([](){
    //     return Robot::GetInstance().getBody().enable();
    // }, [](Error err){});

    // FIXME : I'm putting this comment here because it's important.
    //         There's no movement synchronization like on the previous version
    //         (Getting movement time estimation and going at the slowest motor speed)
    //         This fucks up the body coordination and blocks the robot from walking properly.
    //         Oh, and also check why is the control loop so slow ... It should be around 4ms not 8ms per iteration.
    
    LOG_INFO(TAG, ">>> Robot is operational.");
}
#ifdef __cplusplus
}
#endif

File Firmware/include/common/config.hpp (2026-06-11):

#pragma once
#include <cstdint>
#include <driver/gpio.h>

/** COMPILATION FLAGS **/
#define DEBUG_MODE 1  // 1 to enable debug logs and behaviors, 0 to disable

/** MULTICORE SETUP */
constexpr int CORE_BRAIN = 0;
constexpr int CORE_REFLEX = 1;
// number of milliseconds before triggering security stop (in case brain core crashes, to clear control intent)
constexpr uint32_t CONTROL_INTENT_WATCHDOG_MS = 500;

/** OTA SETUP **/
constexpr const char* OTA_FIRMWARE_LATEST_URL = "https://api.tny-robotics.com/firmware/latest";
constexpr const char* OTA_FILESYSTEM_DOWNLOAD_URL = "https://cdn.tny-robotics.com/firmware/tny-360/%s/filesystem.bin";
constexpr int OTA_UPDATE_TIMEOUT_MS = 5000;
constexpr int OTA_UPDATE_FILESYSTEM_BUFFER_SIZE = 4096; // in bytes
constexpr const char* OTA_ROBOT_MODEL = "tny-360";


/** PHYSICAL INFORMATIONS **/
constexpr float LEG_THIGH_LENGTH_M = 0.100f; // in meters
constexpr float LEG_CALF_LENGTH_M = 0.100f; // in meters
constexpr float HIP_OFFSET_M = 0.034f; // in meters
constexpr float HIP_POS_X_M = 0.086f; // in meters, from body center
constexpr float HIP_POS_Y_M = 0.052f; // in meters, from body center

/** DEFAULT POSE INFORMATIONS **/
constexpr float DEFAULT_BODY_HEIGHT_M   = 0.120f; // in meters, from ground level
constexpr float DEFAULT_FEET_SPREAD_X_M = 0.090f; // in meters, from body center
constexpr float DEFAULT_FEET_SPREAD_Y_M = 0.100f; // in meters, from body center


/** LOGGING **/
// Maximum number of log lines to store
constexpr int LOG_MAX_LINES = 32;
// Maximum length of each log message
constexpr int LOG_MAX_MSG_LEN = 160;
// Maximum length of log tag
constexpr int LOG_MAX_TAG_LEN = 16;

/** FILESYSTEM **/
// Maximum path length for file operations
constexpr int MAX_PATH_LEN = 128;

/** RPC **/
constexpr int RPC_QUEUE_SIZE = 32; // number of pending RPC jobs (between core 0 and core 1)


/** Wi-Fi **/
// Maximum number of connection retries before giving up
constexpr uint8_t WIFI_MAX_RETRIES = 5;
// Maximum length for SSID and Password
constexpr uint8_t WIFI_MAX_SSID_LEN = 32;
constexpr uint8_t WIFI_MAX_PASSWORD_LEN = 64;
// AP SSID and Password
constexpr const char* WIFI_AP_SSID = "TNY-360";
constexpr const char* WIFI_AP_PASSWORD = ""; // open by default


/** Websocket **/
// Maximum message size for WebSocket frames
constexpr uint16_t WEBSOCKET_MAX_MSG_SIZE = 256; // in bytes


/** Protocol **/
// Maximum number of pending protocol commands
constexpr uint8_t PROTOCOL_MAX_PENDING_COMMANDS = 32;
// Maximum number of commands in the protocol
constexpr uint8_t PROTOCOL_MAX_COMMANDS_HANDLERS = 255;


/** I2C **/
// Primary I2C GPIO pins (for critical modules, like sensors)
constexpr gpio_num_t I2C_PRIMARY_SDA_GPIO_NUM = GPIO_NUM_21;
constexpr gpio_num_t I2C_PRIMARY_SCL_GPIO_NUM = GPIO_NUM_47;
// Secondary I2C GPIO pins (for less critical modules, like screens)
constexpr gpio_num_t I2C_SECONDARY_SDA_GPIO_NUM = GPIO_NUM_9;
constexpr gpio_num_t I2C_SECONDARY_SCL_GPIO_NUM = GPIO_NUM_48;


/** Analog Readings **/
// EMA filter alpha value (1.0 = no filtering, 0.1 = big inertia)
constexpr float ANALOG_EMA_ALPHA = 0.05f;

/** Timer management **/
// Control loop frequency
constexpr int CONTROL_LOOP_FREQ_HZ = 200; // Hz
// Resolution of the control loop timer
constexpr int TIMER_RESOLUTION = 1'000'000; // 1Mhz, 1 us
// [][] calculated values below, do not edit manually
constexpr int TIMER_ALARM_COUNT = TIMER_RESOLUTION / CONTROL_LOOP_FREQ_HZ;
constexpr float CONTROL_LOOP_DT_S = 1.0f / CONTROL_LOOP_FREQ_HZ;
constexpr int CONTROL_LOOP_DT_MS = static_cast<int>(CONTROL_LOOP_DT_S * 1000);

// Decision loop frequency
constexpr int DECISION_LOOP_FREQ_HZ = 30; // Hz
constexpr float DECISION_LOOP_DT_S = 1.0f / DECISION_LOOP_FREQ_HZ;
constexpr int DECISION_LOOP_DT_MS = static_cast<int>(DECISION_LOOP_DT_S * 1000);

/** Analog scanner **/
// GPIO pins for the 4-bit multiplexer select lines
constexpr gpio_num_t SCANNER_SLCT_PIN1 = GPIO_NUM_39;
constexpr gpio_num_t SCANNER_SLCT_PIN2 = GPIO_NUM_40;
constexpr gpio_num_t SCANNER_SLCT_PIN3 = GPIO_NUM_41;
constexpr gpio_num_t SCANNER_SLCT_PIN4 = GPIO_NUM_42;


/** LEG **/
// Voltage threshold at which the leg is considered as grounded (touching ground)
constexpr float LEG_GROUNDED_THRESHOLD_V = 2.0f;


/** IMU **/
// I2C address for the IMU (MPU6050)
constexpr uint8_t IMU_I2C_ADDR = 0x68;
// I2C clock speed for IMU communication
constexpr uint32_t IMU_I2C_CLOCK = 400'000; // Hz
// number of samples to gather for calibration
constexpr uint16_t IMU_NB_CALIB_SAMPLES = 100;
// NOTE : Internal robot imu update is driven by the main timer at 200Hz
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

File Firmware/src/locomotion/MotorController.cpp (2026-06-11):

#include "locomotion/MotorController.hpp"
#include "common/Log.hpp"
#include "Robot.hpp"
#include <cstdio>

constexpr const char* TAG = "MotorController";

MotorController::MotorController() {}

MotorController::MotorController(MotorDriver::Channel motor_channel, AnalogDriver::Channel analog_channel, MotorAttributes attribs)
    : motor_channel(motor_channel),
      analog_channel(analog_channel),
      motor_attributes(attribs),
      calibration_state(CalibrationState::UNCALIBRATED),
      state(State::DISABLED),
      target_position(0.5f),
      nvshandle_ptr(nullptr)
{
    // set default pwm bounds to motor attributes
    calibration_data.dc_min = motor_attributes.dc_min;
    calibration_data.dc_max = motor_attributes.dc_max;
    disable(); // make sure motor is off by default
}

Error MotorController::init()
{
    // Check if below drivers are initialized
    LOG_SCOPE(TAG, "MotorController::init [driver=%u, reader=%u]", motor_channel, analog_channel);

    if (Error err = MotorDriver::Init(); err != Error::None)
    {
        state = State::ERROR;
        return err;
    }
    if (Error err = AnalogDriver::Init(); err != Error::None)
    {
        state = State::ERROR;
        return err;
    }

    // Try to read calibration data from NVS
    if (Error err = NVS::Init(); err != Error::None)
    {
        state = State::ERROR;
        return err;
    }
    char key[32]; // using motorChannel as identifier
    sprintf(key, "MtrCtrl-%d", static_cast<int>(motor_channel));
    if (Error err = NVS::Open(key, &nvshandle_ptr); err != Error::None)
    {
        state = State::ERROR;
        LOG_ERROR(TAG, "Failed to open NVS handle for motor channel %d with error [%s]", motor_channel, ErrorToString(err));
        ErrorHandle(ErrorStruct::MotorControllerInitFailed);
        return err;
    }
    if (nvshandle_ptr->get("calib_data", calibration_data) == Error::None)
    {
        LOG_INFO(TAG, "Calibration data loaded from NVS for motor channel %d", motor_channel);
        state = State::ENABLED;
        calibration_state = CalibrationState::CALIBRATED;
    }
    else
    {
        LOG_WARNING(TAG, "No calibration data found");
        calibration_state = CalibrationState::UNCALIBRATED;
    }

    // Disable motor initially
    disable();
    
    return Error::None;
}

Error MotorController::deinit()
{
    if (nvshandle_ptr)
    {
        NVS::Close(nvshandle_ptr);
        nvshandle_ptr = nullptr;
    }

    return Error::None;
}

Error MotorController::enable()
{
    state = State::ENABLED;
    __send_target_position(); // effective right now
    return Error::None;
}

Error MotorController::disable()
{
    state = State::DISABLED;
    __send_target_position(); // effective right now
    return Error::None;
}

Error MotorController::startCalibration()
{
    LOG_INFO(TAG, "Starting motor calibration");

    if (calibration_state == CalibrationState::CALIBRATING)
    {
        LOG_WARNING(TAG, "Motor is already in calibration mode");
        return Error::InvalidState;
    }

    if (BaseType_t err = xTaskCreatePinnedToCore([](void* param) {
            // Stop the control loop and take over for the calibration
            ControlLoop& ctrl = Robot::GetInstance().getControlLoop();
            bool wasRunning = ctrl.isRunning();
            if (wasRunning)
            {
                LOG_DEBUG(TAG, "Disabling control loop");
                if (Error err = ctrl.stop(); err != Error::None)
                {
                    LOG_ERROR(TAG, "Failed to stop control loop for motor calibration. Error [%s]", ErrorToString(err));
                    return;
                }
            }

            MotorController* controller = static_cast<MotorController*>(param);
            controller->calibration_state = CalibrationState::CALIBRATING;
            Error err = controller->run_calibration_sequence();
            if (err != Error::None)
            {
                LOG_ERROR(TAG, "Motor calibration with error [%s]", ErrorToString(err));
                controller->calibration_state = CalibrationState::ERROR;
            }
            else
            {
                LOG_INFO(TAG, "Motor calibrated");
                controller->calibration_state = CalibrationState::CALIBRATED;
            }
            // disable motor for safety
            if (Error err = controller->disable(); err != Error::None)
            {
                LOG_ERROR(TAG, "Failed to disable motor after calibration. Error [%s]", ErrorToString(err));
            }

            // Restart the control loop (back to normal operation)
            if (wasRunning)
            {
                LOG_DEBUG(TAG, "Restarting control loop");
                if (Error err = Robot::GetInstance().getControlLoop().start(); err != Error::None)
                {
                    LOG_ERROR(TAG, "Failed to start control loop after motor calibration. Error [%s]", ErrorToString(err));
                    return;
                }
            }

            // clean up task handle
            vTaskDelete(nullptr);
        }, "MotorCalib", 4096, this, tskIDLE_PRIORITY + 1, &calibration_task_handle, CORE_BRAIN); err != pdPASS)
    {
        LOG_ERROR(TAG, "Failed to create motor calibration task. Error %d", err);
        return Error::SoftwareFailure;
    }

    return Error::None;
}

Error MotorController::stopCalibration()
{
    if (calibration_state != MotorController::CalibrationState::CALIBRATING)
    {
        return Error::InvalidState;
    }

    if (calibration_task_handle != NULL)
    {
        vTaskDelete(calibration_task_handle);
        deleteCalibrationData(false); // reset calibration data but don't save to NVS
        LOG_WARNING(TAG, "Stopped motor calibration. This could lead to unexpected behavior.");
    }

    return Error::None;
}

Error MotorController::setCalibrationData(CalibrationData& data, bool save)
{
    calibration_data = data;
    calibration_state = CalibrationState::CALIBRATED;
    if (save)
    {
        if (Error err = save_calibration_data(); err != Error::None)
        {
            return err;
        }
    }
    return Error::None;
}

Error MotorController::deleteCalibrationData(bool save)
{
    calibration_state = CalibrationState::UNCALIBRATED;
    calibration_data.dc_min = motor_attributes.dc_min;
    calibration_data.dc_max = motor_attributes.dc_max;
    if (save)
    {
        if (Error err = delete_calibration_data(); err != Error::None)
        {
            return err;
        }
    }
    return Error::None;
}

Error MotorController::setCalibrationState(CalibrationState state)
{
    LOG_WARNING(TAG, "Manually changing calibration state to [%d]. This could lead to unexpected behavior.", static_cast<uint8_t>(state));
    calibration_state = state;
    return Error::None;
}
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

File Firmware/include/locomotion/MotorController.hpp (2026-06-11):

#pragma once
#include "drivers/MotorDriver.hpp"
#include "drivers/AnalogDriver.hpp"
#include "common/NVS.hpp"
#include <freertos/FreeRTOS.h>
#include <freertos/task.h>

class MotorController
{
public:
    enum class State : uint8_t
    {
        ENABLED = 1,
        DISABLED = 0,
        ERROR = 2,
    };

    enum class CalibrationState : uint8_t
    {
        UNCALIBRATED = 0,
        CALIBRATING = 1,
        CALIBRATED = 2,
        ERROR = 3,
    };

    struct MotorAttributes
    {
        MotorDriver::Value dc_min;
        MotorDriver::Value dc_max;
        bool has_feedback;
    };

    constexpr static MotorAttributes MOTOR_ATTR_MG996R = {
        .dc_min = 0.5f, // 0.5us duty cycle
        .dc_max = 2.5f, // 2.5us duty cycle
        .has_feedback = true
    };

    constexpr static MotorAttributes MOTOR_ATTR_SG90 = {
        .dc_min = 1.0f, // 1.0us duty cycle
        .dc_max = 2.0f, // 2.0us duty cycle
        .has_feedback = false
    };

    struct CalibrationData
    {
        /// @brief Minimum Duty Cycle value corresponding to the minimum physical position of the motor
        MotorDriver::Value dc_min = 0.5f;
        /// @brief Maximum Duty Cycle value corresponding to the maximum physical position of the motor
        MotorDriver::Value dc_max = 2.5f;
        /// @brief Deadband width in Duty Cycle unit
        MotorDriver::Value dc_deadband = 0;
        /// @brief Feedback value corresponding to the minimum physical position of the motor
        AnalogDriver::Value feedback_min = 0.5f;
        /// @brief Feedback value corresponding to the maximum physical position of the motor
        AnalogDriver::Value feedback_max = 2.8f;
        /// @brief Feedback noise level in Volt (standard deviation)
        AnalogDriver::Value feedback_noise = 0;
        /// @brief Latency between command and movement in ms
        float feedback_latency_ms = 0;
        /// @brief Flag indicating whether the feedback is inverted (low voltage for max position, high voltage for min position)
        bool feedback_inverted = false;
        /// @brief Maximum speed of the motor (in progress per second, where progress is the distance between min and max bound)
        float max_speed = 0.f;
    };

    MotorController();
    
    MotorController(MotorDriver::Channel motor_channel, AnalogDriver::Channel analog_channel, MotorAttributes attribs = MOTOR_ATTR_MG996R);

    /**
     * @brief Initialize the motor controller.
     * @return Error code indicating success or failure.
     */
    Error init();

    /**
     * @brief Deinitialize the motor controller.
     * @return Error code indicating success or failure.
     */
    Error deinit();

    /**
     * @brief Turns on the motor.
     * @return Error code indicating success or failure.
     */
    Error enable();

    /**
     * @brief Turns off the motor.
     * @return Error code indicating success or failure.
     */
    Error disable();

    /**
     * @brief Starts the calibration process.
     * @return Error code indicating success or failure.
     */
    Error startCalibration();

    /**
     * @brief Stops the calibration process (no saving).
     * @note This method should not be called to save calibration data, it is done automatically on calibration sequence completion.
     * @return Error code indicating success or failure.
     */
    Error stopCalibration();

    /**
     * @brief Get the calibration progress as a ratio (0.0 to 1.0).
     * @return Calibration progress.
     */
    float getCalibrationProgress() const { return calibration_progress; }

    /**
     * @brief Set the calibration state.
     * @param state New calibration state.
     * @return Error code indicating success or failure.
     * @note Should only be used for manual calibration control. 
     */
    Error setCalibrationState(CalibrationState state);

    /**
     * @brief Get the current calibration data
     * @return Current calibration data
     */
    const CalibrationData& getCalibrationData() const { return calibration_data; }

    /**
     * @brief Set the current calibration data
     * @param data The CalibrationData object to set
     * @param save Should the data be saved in NVS for future use
     * @return If the save was successfull or not
     */
    Error setCalibrationData(CalibrationData& data, bool save = true);

    /**
     * @brief Delete the current calibration data (fallback to default)
     * @param save Should the deletion be saved in NVS or not
     * @return If the deletion was successfull or not
     */
    Error deleteCalibrationData(bool save = true);

    /**
     * @brief Set the target position for the motor.
     * @param position Target position as a ratio (0.0 to 1.0).
     * @note An approximate position can be set even if the motor is uncalibrated.
     * @return Error code indicating success or failure.
     */
    Error setTargetPosition(float position);

    /**
     * @brief Get the target position of the motor.
     * @param result Target position as a ratio (0.0 to 1.0).
     * @return Error code indicating success or failure.
     */
    Error getTargetPosition(float& result) const;

    /**
     * @brief Get the current position of the motor.
     * @param result Current position as a ratio (0.0 to 1.0).
     * @return Error code indicating success or failure.
     * @note An approximate position will be returned until the motor is calibrated.
     */
    Error getCurrentPosition(float& result) const;

    /**
     * @brief Get the current state of the motor controller.
     * @return Current state.
     */
    State getState() const { return state; }

    /**
     * @brief Get the current state of calibration.
     * @return Current calibration state.
     */
    CalibrationState getCalibrationState() const { return calibration_state; }

    /**
     * @brief Get the motor channel.
     * @return Motor channel.
     */
    MotorDriver::Channel getMotorChannel() const { return motor_channel; }

    /**
     * @brief Get the analog channel.
     * @return Analog channel.
     */
    AnalogDriver::Channel getAnalogChannel() const { return analog_channel; }

private:
    MotorDriver::Channel motor_channel;
    AnalogDriver::Channel analog_channel;

    MotorAttributes motor_attributes;
    CalibrationData calibration_data;
    CalibrationState calibration_state;
    float calibration_progress;
    
    State state;
    float target_position = 0;
    NVS::Handle* nvshandle_ptr;

    TaskHandle_t calibration_task_handle;

    Error __send_target_position();
    Error save_calibration_data();
    Error delete_calibration_data();
    Error run_calibration_sequence();
};

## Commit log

2026-03-16 Updated Torso model for new PCBs
    [Torso.FCStd]
2026-03-31 Added aliexpress version info in BOM
2026-04-04 Fixed a lot of details, added back & battery parts
    [Back.FCStd, Battery Pack.FCStd, Battery.FCStd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]
2026-04-09 Updated CAD settings
    [Settings.FCStd]
2026-04-09 Added double-side pad for servo pcb
    In case of reversed-potentiometer in MG996R motors
    [BOM.xlsx, PickAndPlace.xlsx]
2026-04-19 Removed useless stl exports
    [Servo Cover.stl]
2026-04-22 Fixed missaligned holes on torso
    [Back - Cover.stl, Back.FCStd, Head - Top Cover.stl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]
2026-04-29 Improved back cover model
    [Torso - Cover Attach.stl, Torso.FCStd]
2026-04-29 [WIP] Started camera driver
2026-05-07 Fixed lots of things and started others
    - Fixed compilation errors
    - Started new motor calibration
    - Fixed and improved IK & Control Loop
    [partitions.csv]
2026-05-07 Fixed fkd up flags + minor changes
    [ControlLoop.cpp, Joint.cpp]
2026-05-10 Improved motor calibration
2026-05-11 Uploaded PCB Schematics
2026-05-13 Fixed calibration sequence and added power logs
    [MenuBootCalibration.cpp, main.cpp]
2026-05-14 Added "skipping" text on boot skips
    [MenuBootCalibration.cpp]
2026-05-14 Fixed bugs and details + back to 200Hz
    [MenuBootCalibration.cpp, config.hpp]
2026-05-20 Added .4mm to decrease joint gap
    [Leg - Top BL.stl, Leg - Top BR.stl, Leg - Top FL.stl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]
2026-05-20 Removed Zero-Calib and smoothed ADC readings
2026-05-31 Squashed commit of the following:
    commit e8f27095950559b56dd6dd8a94d10d5d7f7af056
    Author: Paul LOISIL <fur.waz06@gmail.com>
    Date: Sun May 31 19:15:50 2026 +0200
    Improved web dashboard
    commit a34f98cd5e0dad13fc1b2c0596cae5091098b792
    Author: Paul LOISIL <fur.waz06@gmail.com>
    Date: Sun May 31 19:15:36 2026 +0200
    Fixed wrong walking gait at startup
    commit 5101f0a0e51eebaf248bc6eb4aa66acf4c83a41d
    Author: Paul LOISIL <fur.waz06@gmail.com>
    Date: Sun May 31 19:15:17 2026 +0200
    Improved logs & added leg override
    commit 52dddeac4547c992cc9f6d9daca949733c988c77
    Author: Paul LOISIL <fur.waz06@gmail.com>
    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
    [ControlLoop.cpp, IMUDriver.cpp, Joint.cpp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]
2026-06-11 Squashed commit of the following:
    commit 042bf5774ee84511db5502b0d2e0f014c4573505
    Date: Thu Jun 11 18:41:16 2026 +0200
    Fixed bugs, refactored & Added Motor + System methods
    commit c5b9480114d783ad99229b1ce3a12848e49040f0
    Date: Wed Jun 10 15:38:06 2026 +0200
    Fixed slight tilt in [Leg-Top Deco Bottom L] part
    commit 9628480599c2806fdfe26e940fc00197511a99c6
    Date: Tue Jun 9 09:14:24 2026 +0200
    Added Gauge and Test parts in .3mf file
    commit fc86d56d35d1d1f83f7fb5a86db83fd5a17f7720
    Date: Tue Jun 9 09:13:49 2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
    [ControlLoop.cpp, MotorController.cpp]
2026-06-28 Fix PlatformIO build: resolve submodule paths
    [SerialTransport.cpp]
2026-06-30 Fix formatting for planned active cooling details
    Corrected formatting for fan description in the Planned section.
2026-06-30 Add Spacer.FCStd
    Spacer goes under the top cover to prevent cables from getting pinched.
    [Spacer.FCStd]

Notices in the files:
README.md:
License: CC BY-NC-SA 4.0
